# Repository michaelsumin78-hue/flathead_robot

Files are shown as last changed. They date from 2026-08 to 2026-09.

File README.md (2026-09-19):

# Flathead Autonomous Quadruped

3D printed Autonomous Quadruped robot using camera vision, all inspired by the Cyberpunk 2077 flathead robot.



# Demo Link:

https://drive.google.com/file/d/12_6V4TeB604TGq49_DJ_Ktc-aOF2DAQ_/view?usp=drive_link

# CAD Model


This shows the model while viewing fusion. The robot for the most part is printed in 2 main separate pieces and is put together using m4 screws. The robot is made up of the front containing the head which will contain the main electronics and the back end containing the battery. To connect the servos together, aluminum servo horns are used for ideal strength and for ease of use.

# Wiring


Attached is a basic preview of what the wiring will look like for the flathead. A more detailed file can be found in the wiring branch of this project's repository but it is included here to display how it works. As shown, the project will mostly be running off of two separate step down converters, one end for the servos and the other for the brain, which will handle the raspberry pi, esp32, and all other fundamental parts to keep the robot running.

# Features:

(Work in progress)

-Quadruped robot with 3DOF per leg

-Robot uses AI vision through the Pi camera to navigate its envrionment

-Robot uses AI and Elevenlabs to simulate a rogue AI from Cyberpunk 2077 and can be spoken to

-LEDs light up the front of the robot

-Robotic arms with 3DOF per arm to pick up items

# How to run it locally:

Available now — leg inverse kinematics (no hardware required):

Requires g++ (C++11 or later).

    git clone https://github.com/michaelsumin78-hue/flathead_robot.git
    cd flathead_robot/flathead-quadruped_code
    g++ -O2 -o test_ik test_ik.cpp
    ./test_ik

Expected output: round-trip error of 0.0000mm on every test case, plus
standing pose a swing phase sweep

# Coming once the hardware is built:

[ ] ESP32-S3 firmware flash (PlatformIO project, board config TBD)

[ ] Gait engine running on hardware

[ ] Pi-side vision and voice pipeline setup

[ ] Full bring-up sequence: power-on order, safety checks, first servo test

# How I made this:
The leg geomoetry went through several revisions driven primarily by torque calculation. To add on, the project was initially intended to use dog-like leg structure but I decided to scrap that and redo the legs after looking at in game footage of the robot in Cyberpunk and seeing videos of people developing spider robots that use a different degree of rotation. When I redid, I changed the leg design visually in many ways, but I also added a slot to have a TPU printed part at the soles of the feet to allow more friction and therefore allow the robot to walk easier.

The overall body was developed by using a 3D model to look around the entire body and see how I should model the robot to remain faithful to the game. I did however have to take some creative liberties of my own as I realized that certain parts of the in game robot were not desirable in my project. I added more interior space to have more room for the electronics, cut out parts of the front to have LEDS visible, adjusted certain parts to be longer or shaped differently to hold motors and what not. I also had to slice the robot in half between the leg and the back torso containing the battery as I realized not only would most commercial printers not be able to print the entire thing in one sitting because of the robot's length, but it would also take far too long as just the front of the bot takes 14 hours optimally to print.

Credits:
https://grabcad.com/library/rack-and-pinion-gear-precision-linear-motion-cad-assembly-mechanical-power-transmission-design-1 

Credit to Muhammad Qasim Sajid for creating the rack and pinion gear which I built part of the arm design off of.

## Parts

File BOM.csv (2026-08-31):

Item | Quantity | Unit Cost | Total Cost | Link
MG996R Servos (5 pack) | 3 | 13.78 | 41.34 | https://www.aliexpress.com/item/3256807209626078.html
MG90 Servos (8 pack) | 1 | 22.93 | 22.93 | https://www.aliexpress.us/item/2251832788499811.html?gatewayAdapt=glo2usa4itemAdapt
TPU Filament | 1 | 9.75 | 9.75 | https://www.aliexpress.com/item/3256811821156628.html
2S 2200mAh 7.4V LiPo | 1 | 16.92 | 16.92 | https://www.amazon.com/gp/product/B0GS2FYJJZ/ref=ox_sc_act_title_27?smid=A1KODDOPEPALCP&psc=1
XT60 Plug | 1 | 8.99 | 8.99 | https://www.amazon.com/gp/product/B07QH249CR/ref=ox_sc_act_title_26?smid=A1JTH8JAMM4IYJ&psc=1l
Buck Converter for Servos | 1 | 1.50 | 1.50 | https://www.aliexpress.com/item/3256809620604479.html
Buck Converter for ESP | 1 | 1.50 | 1.50 | https://www.aliexpress.com/item/3256808644352772.html
4700uF Capacitor | 1 | 0.99 | 0.99 | https://www.aliexpress.us/item/3256804690325267.html
Wire Stripper | 1 | 4.5 | 4.5 | https://www.aliexpress.com/item/3256811776285441.html
Heat Shrink Pack | 1 | 3.24 | 3.24 | https://www.aliexpress.com/item/4000342725090.html
LiPo Voltage Checker | 1 | 4.38 | 4.38 | https://www.aliexpress.com/item/3256808516638043.html
18 Gauge Wire Roll | 1 | 5.00 | 5.00 | https://www.aliexpress.com/item/4000009001537.html
14 Gauge Wire Roll | 1 | 5.00 | 5.00 | https://www.aliexpress.com/item/4000009001537.html
ESP Dev Board | 1 | 3.42 | 3.42 | https://www.aliexpress.com/item/32864722159.html
PETG Filament | 1 | 14.69 | 14.69 | https://www.amazon.com/gp/product/B07PGYHYV8/ref=ox_sc_act_title_16?smid=A3M6OB6YPLO1C&th=1
LiPo Charger | 1 | 37.99 | 37.99 | https://www.amazon.com/gp/product/B0G6KTKQ7F/ref=ox_sc_act_title_15?smid=A96UES7Z1PS0W&psc=1
Raspberry Pi Zero 2W | 1 | 34.99 | 34.99 | https://www.amazon.com/dp/B0FN4CN7TM
Pi Zero Heatsink | 1 | 4.00 | 4.00 | https://www.aliexpress.com/item/1005003821361392.html
Fuse | 1 | 15.99 | 15.99 | https://www.amazon.com/gp/product/B07Q9PL4R6/ref=ox_sc_act_title_12?smid=ATVPDKIKX0DER&th=1
Pi Zero Camera | 1 | 16 | 16 | https://www.amazon.com/gp/product/B07G9VLPZH/ref=ox_sc_act_title_11?smid=A2GK66ZZ8YJ0PV&th=1
Jumper Wires | 1 | 4.48 | 4.48 | https://www.aliexpress.com/item/1005002599108827.html
MAX98357A I2S Amplifier | 1 | 5.52 | 5.52 | https://www.aliexpress.us/item/3256811506362905.html
INMP441 I2S Microphone | 1 | 1.76 | 1.76 | https://www.aliexpress.com/item/32962426410.html
4 Ohm Speaker | 1 | 1.99 | 1.99 | https://www.aliexpress.us/item/3256809279427147.html
PCA9685 PWM Driver | 1 | 2.68 | 2.68 | https://www.aliexpress.com/item/32753750943.html
M3 Hardware Assortment | 1 | 9.99 | 9.99 | https://www.amazon.com/dp/B0FGV5FCBN
MPU6050 IMU | 1 | 11.79 | 11.79 | https://www.amazon.com/dp/B00LP25V1A
Metal Servo Horns | 3 | 4.03 | 12.09 | https://www.aliexpress.com/item/1005003027854823.html
Carbon Film Resistor Kit | 1 | 9.23 | 9.23 | https://www.aliexpress.us/item/2251832604413847.html
RGB LED Diodes 5mm Common Anode | 1 | 8.99 | 8.99 | https://www.amazon.com/gp/product/B09BHSDDZ5/ref=ox_sc_act_title_2?smid=A2FHFF9H7S4EUV&th=1

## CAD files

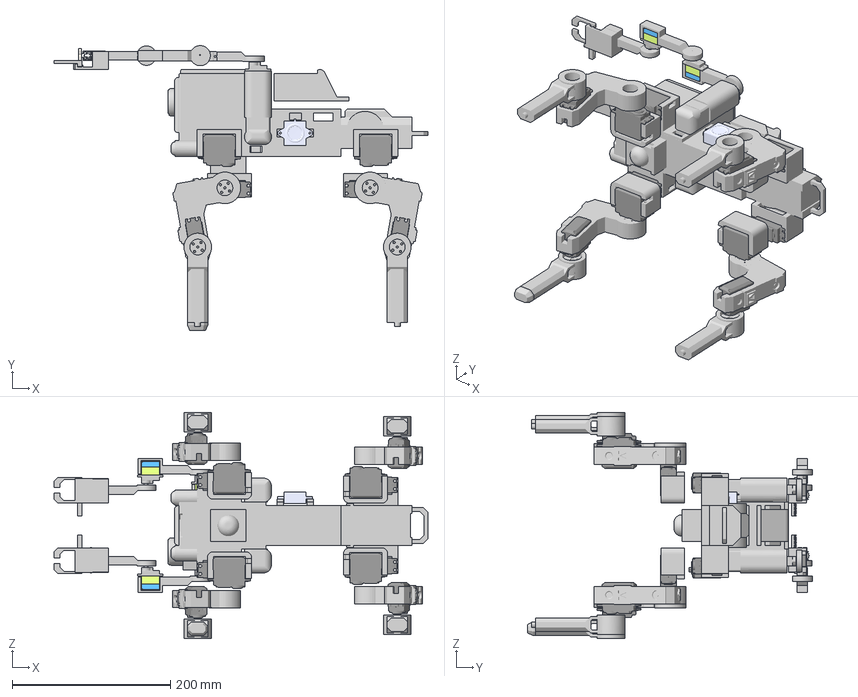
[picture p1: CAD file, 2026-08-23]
flathead_robot_cad/robot_whole.3mf
472.9 x 360.3 x 285.9 mm

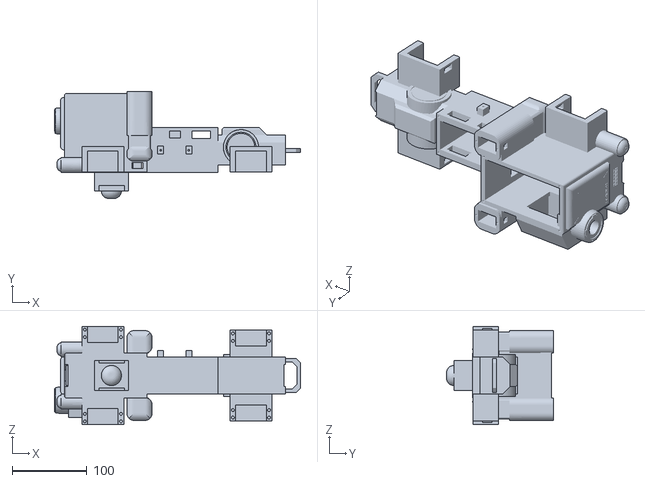
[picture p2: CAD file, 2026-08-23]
flathead_robot_cad/stl/main_body_chassis.stl
328.5 x 142.8 x 131.4

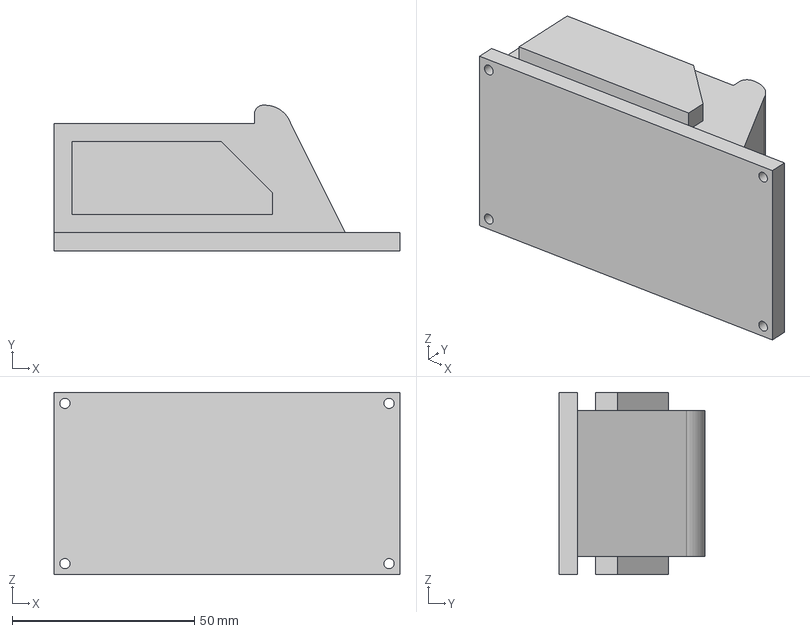
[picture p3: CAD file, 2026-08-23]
flathead_robot_cad/step/roof 2.step
95.0 x 40.0 x 50.0 mm

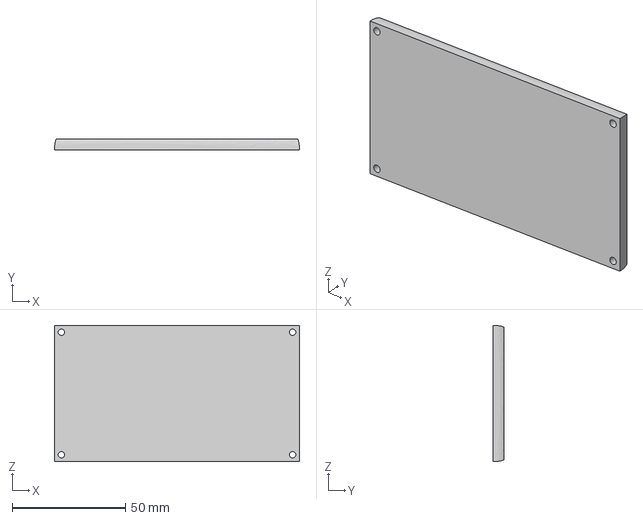
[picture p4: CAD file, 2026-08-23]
flathead_robot_cad/step/roof 1.step
108.0 x 5.00 x 60.0 mm

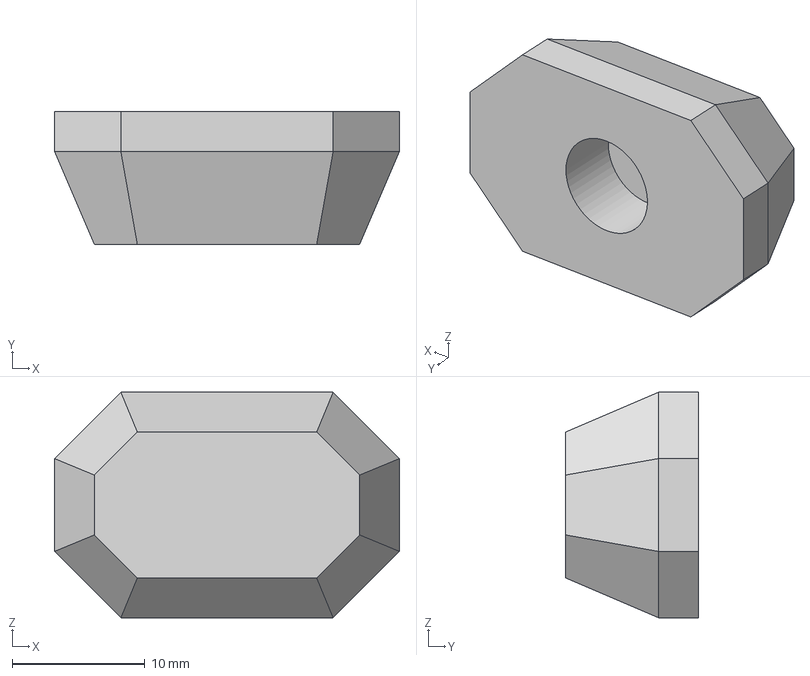
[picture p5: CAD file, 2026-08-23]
flathead_robot_cad/step/robot_toe.step
26.0 x 10.0 x 17.0 mm

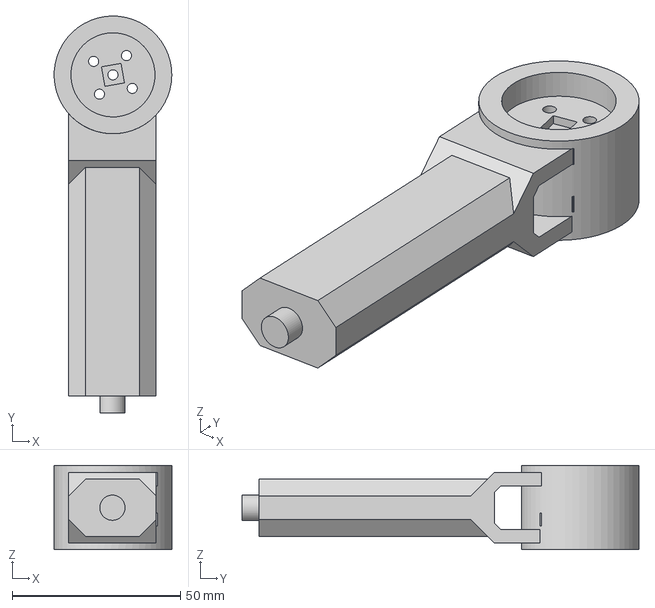
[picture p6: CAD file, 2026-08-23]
flathead_robot_cad/step/rightleg3.step
35.0 x 118.0 x 25.0 mm

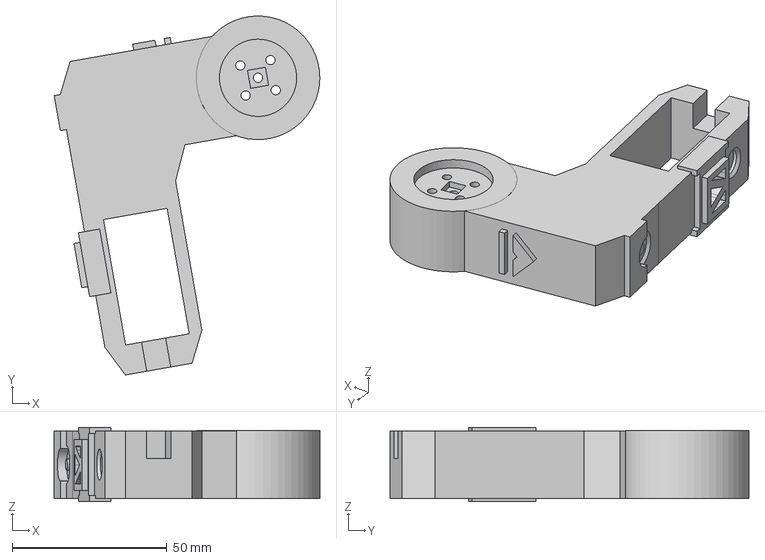
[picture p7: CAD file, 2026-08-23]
flathead_robot_cad/step/rightleg2.step
86.0 x 116.1 x 24.0 mm

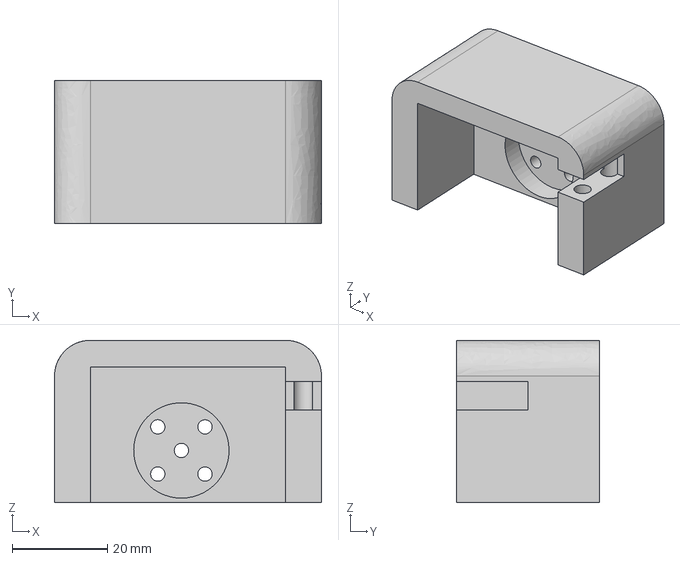
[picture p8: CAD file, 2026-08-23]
flathead_robot_cad/step/rightleg1.step
56.0 x 30.0 x 34.0 mm

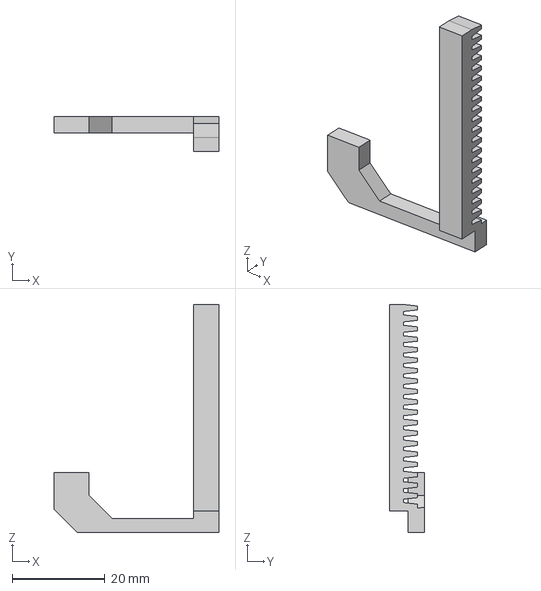
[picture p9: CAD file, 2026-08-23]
flathead_robot_cad/step/right straight gear.step
35.5 x 7.46 x 49.2 mm

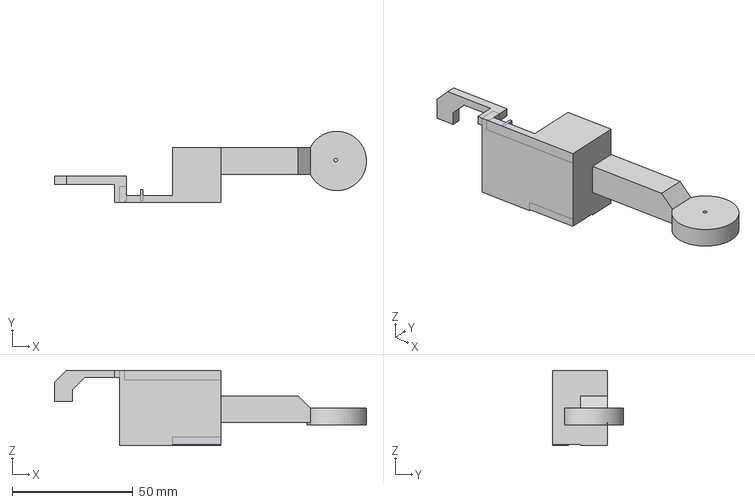
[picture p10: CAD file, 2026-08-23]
flathead_robot_cad/step/right arm 3.step
129.2 x 29.5 x 31.2 mm

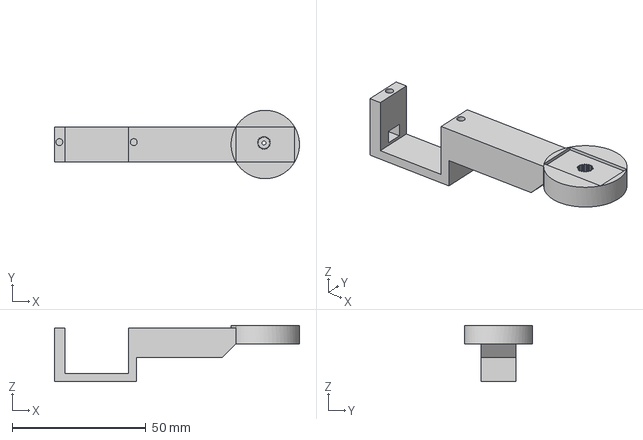
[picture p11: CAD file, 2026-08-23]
flathead_robot_cad/step/right arm 2.step
91.5 x 25.5 x 21.0 mm

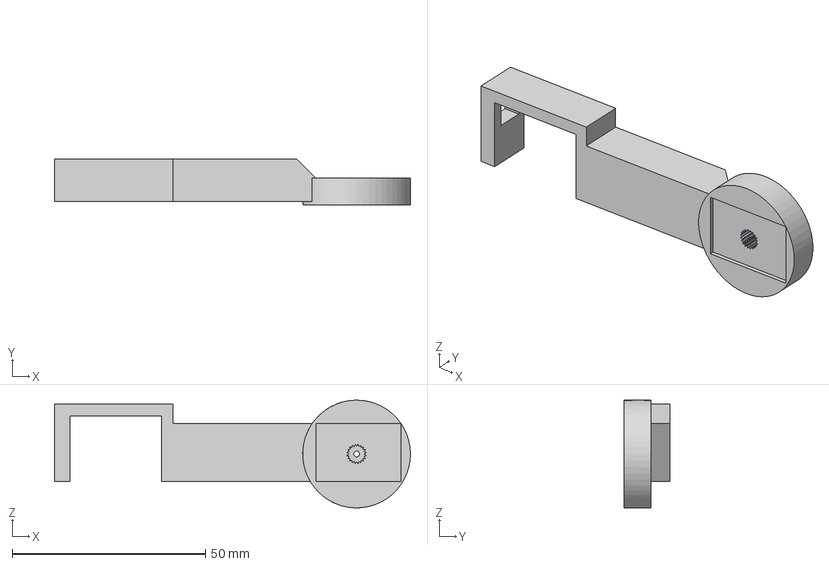
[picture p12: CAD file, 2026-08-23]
flathead_robot_cad/step/right arm 1.step
92.2 x 12.0 x 27.9 mm

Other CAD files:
flathead_robot_cad/step/leftleg3.step
flathead_robot_cad/step/leftleg2.step
flathead_robot_cad/step/leftleg1.step
flathead_robot_cad/step/left straight gear.step
flathead_robot_cad/step/left arm 3.step
flathead_robot_cad/step/left arm 2.step
flathead_robot_cad/step/gear.step
flathead_robot_cad/step/left arm 1.step
flathead_robot_cad/stl/gear.stl
flathead_robot_cad/stl/left_straight_gear.stl
flathead_robot_cad/stl/leftarm1.stl
flathead_robot_cad/stl/leftarm2.stl
flathead_robot_cad/stl/leftarm3.stl
flathead_robot_cad/stl/leftleg1.stl
flathead_robot_cad/stl/leftleg2.stl
flathead_robot_cad/stl/leftleg3.stl
flathead_robot_cad/stl/right_straight_gear.stl
flathead_robot_cad/stl/rightarm1.stl
flathead_robot_cad/stl/rightarm2.stl
flathead_robot_cad/stl/rightarm3.stl
flathead_robot_cad/stl/rightleg1.stl
flathead_robot_cad/stl/rightleg2.stl
flathead_robot_cad/stl/rightleg3.stl
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

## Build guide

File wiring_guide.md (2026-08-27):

Wiring reference

I²C bus
ESP32 GPIO8  → PCA9685 SDA, MPU6050 SDA
ESP32 GPIO9  → PCA9685 SCL, MPU6050 SCL

PCA9685 servo channels
0-2    Front-left   coxa / hip / knee
3-5    Front-right  coxa / hip / knee
6-8    Rear-left    coxa / hip / knee
9-11   Rear-right   coxa / hip / knee
12-15  Arm          yaw / pitch / elbow / gripper
16-19 Arm 2         yaw / pitch / elbow/ gripper

Rails
5.5 V  servo bus (XL4016) to 16 servos, 4700 µF at distribution
5.0 V  logic (UBEC) to ESP32, PCA9685, MPU6050, Pi, mic, amp
GND    all returns to bar at battery negative

Updated Wiring Draft



Closer Look:

[Flathead_Wiring.pdf](https://github.com/user-attachments/files/31533699/Flathead_Wiring.pdf)

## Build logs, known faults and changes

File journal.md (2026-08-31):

| | |
| :--- | :--- |
| **Title** | Flathead |
| **Author** | Mike |
| **Description** | A 12-DOF quadruped that walks, balances, and looks like it crawled out of Night City |
| **Created At** | 2026-08-16 |

Leg Making



This is the first part to the start of my leg design is more of a rough draft. You can see that the design is mainly based off of using metal servo horns. In my experience plastic ones do not last very long and I wanted to be more careful considering the motors I will be using are mg996rs. 



This is where I started mapping out the general shape of the leg. I pulled up a 3d model of the in game version of the robot and tried to model it to get as close as possible while accounting for the lengths of the joints which I tried keeping around 75mm so the math for IK will be easier to do.



Body work done before vacation

This iteration shows what is basically the finished leg design but I made a small iteration at least in the model where the joint is bent backwards(this will not stay). I added holders so along the leg the wiring can stay in place and I started adding the connections required  to allow it to be attached to the main body.

Side Note:
I would also like to say that the leg design of the in game robot would be very difficult to make work and for it to be stable so I took some creative liberties.



The attached image displays some of the final progress I would make before going on vacation. A lot of this will become subject to change but right now I begin to model the front face of the robot.



A lot of this was purely cosmetic and just so I could feel happy about the state of the project before I leave.

Body and Arm Development





I begin to model the back of the robot to be similar to the in game one. Being about happy with the progress for now, I move on to the arm layout. I am using sg90 servo motors here so I import a model I found online and begin modeling the base of the arm around it. I have one yaw at the base and two pitches as I get closer to the front. The arms take less of the focus here so I wanted to make them simpler but I still want them to be functional. 



I import a model of a matching round and straight gear set to develop a rack and pinion gripper design. I begin to develop a mount to keep the straight gear in place while developing the gripper that should move to close in on a object.



This is about the finished version of the model for the arms. I added the static half of the gripper and I spent some time making the arms look better as well as the base for the arms. I also added areas for the wires to go through similar to what I did for the legs.

Side Note:
https://grabcad.com/library/rack-and-pinion-gear-precision-linear-motion-cad-assembly-mechanical-power-transmission-design-1
I have attached the 3d model I used for the rack and pinion gear which I have built upon to be usable in my model. Everything else in the model is either a placeholder asset or made by me.

Side Note: 
I mirrored the leg designs on all sides but it was about one command so I avoided going too in depth on it.

Final Modeling Details



For starters I begin to develop the roof designs for the robot to conceal the electronics that will be placed inside. 



This is where I realized that my original face design for the robot needs to be adjusted, as I needed somewhere to conceal and keep my camera module. I decided to remove the original design I made for the camera and begin making a usable one. I used a raspberry pi camera placeholder and modeled around it while trying to keep the original essence of the design.





I finish the overall looks of the outside of the camera and decide to move it more inward into the design. You can see the result of this by me carving out a space in the inner space of the front of the robot where you can slot in the camera. 





Considering the importance of the gyroscope and me wrapping things up, I made a holder for the gyroscope to keep it in place.



This is the compartment the battery will be going and I added small latches to keep the battery in place as considering it is a lipo, more care needs to be put into it. 



For the finishing touches I added somewhere to keep the speaker in place on the outside to project the robot's voice better and I also made a couple more adjustments to the back to make it more visually appealing.

Leg Redesign



I have spent some time improving the leg design in both form and lengths for femur and tibia. I have added a component that I intend to be printed in TPU at the feet in order to keep friction at the feet.

Firmware Log 1:

Before touching hardware, I wrote the core math the robot depends on to convert a target foot position into the three joint angles to reach it. I wrote a desktop test that does not need a microcontroller or servos to test every case. It solves IK for the target and pushes the resulting angle back through forward kinematics and check if the foot lands within 0.01mm of where it was supposed to go. Every case passed with close to no error which is good considering that while in action it will obviously be slightly less efficient and accurate, it should provide close to no margin of error considering how accurate it is now. I decided to develop this as a sanity check to have zero hardware risk so I will be ready and prepared before I start working with physical parts.

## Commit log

2026-08-15 Create BOM
2026-08-15 Update BOM
2026-08-15 Create wiring
2026-08-16 Update and rename BOM to BOM.md
2026-08-17 Create wiring diagram
2026-08-17 Update wiring
2026-08-23 Create left arm 1.step
    [left arm 1.step]
2026-08-23 Create left arm 2.step
    [left arm 2.step]
2026-08-23 Create left arm 3.step
    [left arm 3.step]
2026-08-23 Create left straight gear.step
    [left straight gear.step]
2026-08-23 Create right arm 1.step
    [right arm 1.step]
2026-08-23 Create right arm 2.step
    [right arm 2.step]
2026-08-23 Create right arm 3.step
    [right arm 3.step]
2026-08-23 Create right straight gear.step
    [right straight gear.step]
2026-08-23 Create roof 1.step
    [roof 1.step]
2026-08-23 Create roof 2.step
    [roof 2.step]
2026-08-26 Update and rename BOM.md to BOM.csv
    [BOM.csv]
2026-10-22 Rev G wiring, second PCA9685, README formatting and BOM table
    - Add KiCad project (wiring/): 2nd PCA9685 at 0x41 for arm 2, RGB eye LEDs,
    plain ESP32 pinout, power switch, fixed battery divider wiring
    - BOM: 2x PCA9685, owned switch and microSD rows, Notes column, header on line 1
    - wiring_guide.md rewritten for Rev G
    - README: markdown formatting, typos, wiring image from repo, BOM table
2026-10-22 BOM: add AliExpress shipping
2026-10-22 BOM: verified Amazon prices, replace unavailable LiPo, Amazon shipping
2026-10-22 BOM: signed-in AliExpress prices, replace MG90 and wire listings, option notes
2026-10-22 BOM: real Pi Zero 2 W listing
2026-10-22 BOM: AliExpress shipping from per-listing rates
